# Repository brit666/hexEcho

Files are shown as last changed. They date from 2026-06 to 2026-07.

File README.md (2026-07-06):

# HexEcho 

Hexapod Assembly (rendered)

**Autonomous 18-DOF Hexapod Robot with Ultrasonic Navigation**

HexEcho is a fully autonomous six-legged walking robot built from scratch — custom CAD, hand-wired electronics, and original firmware. It uses a wave gait for maximum stability and an HC-SR04 ultrasonic sensor for obstacle detection and avoidance.

Built as a course project and designed as the physical platform for future reinforcement learning research.

---

## Quick Overview

| Property | Value |
|---|---|
| DOF | 18 (3 per leg × 6 legs) |
| Gait | Wave gait (1 leg at a time, 5 always grounded) |
| Controller | Arduino Nano |
| Servo Driver | 2× PCA9685 (I²C, 0x40 / 0x41) |
| Sensor | HC-SR04 ultrasonic |
| Power | 2S LiPo 7.4V 1000mAh |
| Chassis | Custom PETG, 3D printed |
| Weight | ~600g |

---

## Repository Structure

```
HexEcho/
├── firmware/
│   └── HexEcho_firmware.ino       # Main Arduino sketch
├── CAD/
│   ├── source/                    # Fusion 360 .f3d files
│   └── stl/                       # Export STLs for printing
│       ├── body_cylinder.stl
│       ├── cover_plate.stl
│       ├── body_hook.stl
│       ├── coxa_bracket.stl
│       ├── femur.stl
│       └── tibia.stl
│       └── print_details.txt
├── schematics/
│   └── HexEcho_schematic.png      # EasyEDA circuit diagram
├── docs/
│   └── HexEcho_Build_Manual.pdf  # Complete build manual (start here)
├── README.md
└── LICENSE
```

---

## Getting Started

Read **[`docs/HexEcho_Build_Manual.pdf`](docs/HexEcho_Build_Manual.pdf)** — it covers the full bill of materials, mechanical specs, wiring, firmware architecture, assembly steps, and calibration in detail.

**Quick steps:**
1. Print all STL files per the print settings in the manual
2. Source components from the BOM
3. Wire per the schematic
4. Flash `HexEcho_firmware.ino` to the Arduino Nano
5. Calibrate home angles and PWM range, then tune gait parameters
6. Deploy

---

## Dependencies

Install via Arduino IDE Library Manager before flashing:

- [Adafruit PWMServoDriver](https://github.com/adafruit/Adafruit-PWMServoDriver-Library)
- `Wire.h` (built-in)

---

## Roadmap

- **v1.0** — Wave gait + ultrasonic obstacle avoidance ✅ *(current)*
- **v2.0** — Reinforcement learning locomotion via Unreal Engine sim-to-real
- **v3.0** — Onboard camera + visual navigation
- **v4.0** — Adaptive terrain locomotion

---

## License

MIT License — see [LICENSE](LICENSE).

Hexapod Assembly pic trans


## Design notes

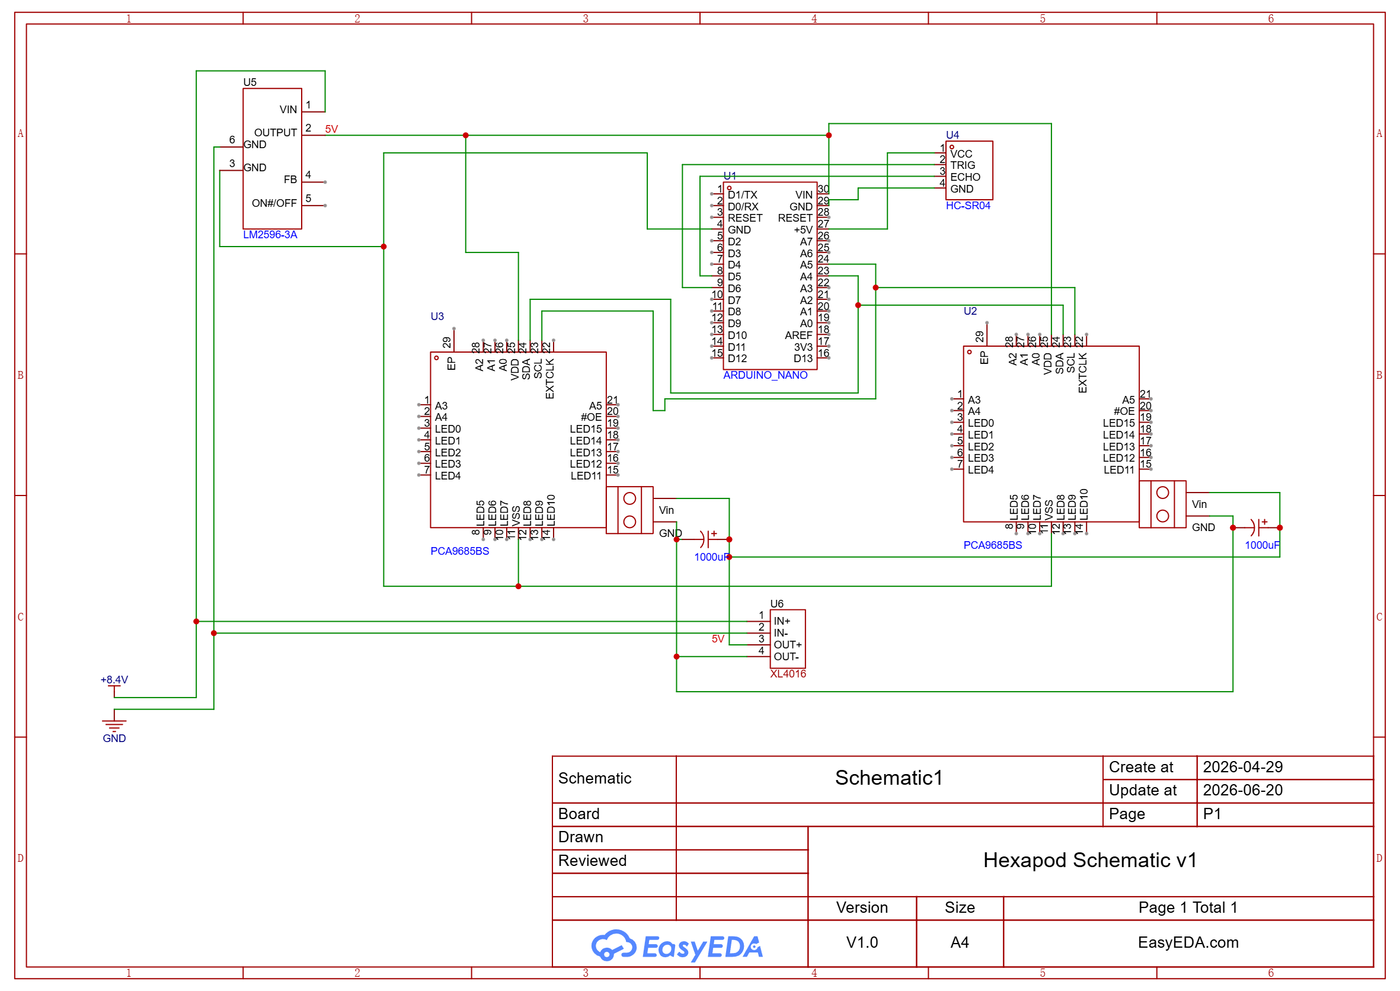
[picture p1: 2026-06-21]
schematics/HexEcho_schematic.png

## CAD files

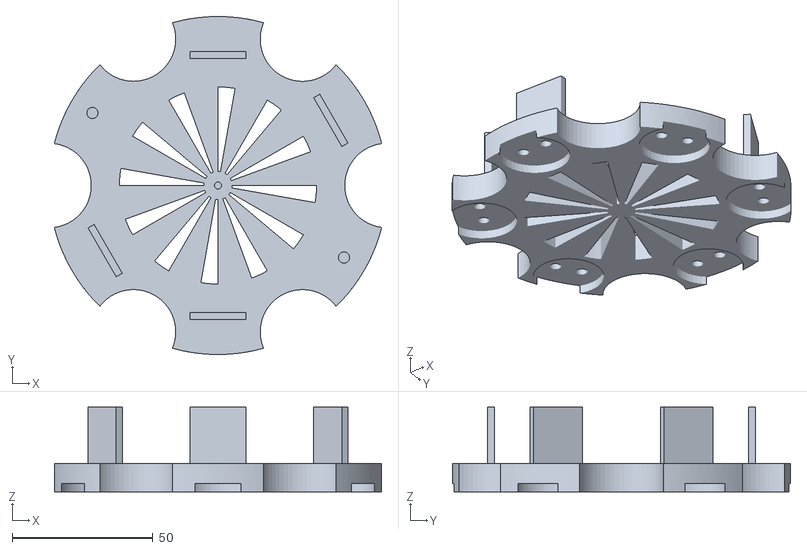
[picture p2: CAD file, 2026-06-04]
cad/stl/body_cylinder.stl
116.2 x 120.0 x 30.0

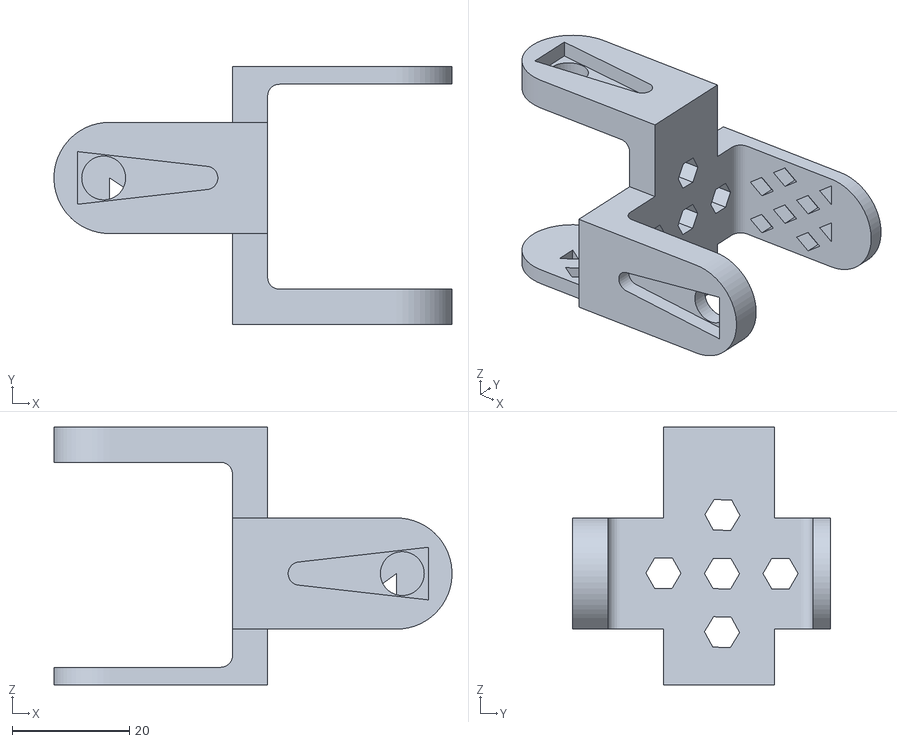
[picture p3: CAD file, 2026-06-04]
cad/stl/coxa_bracket.stl
68.0 x 44.0 x 44.0

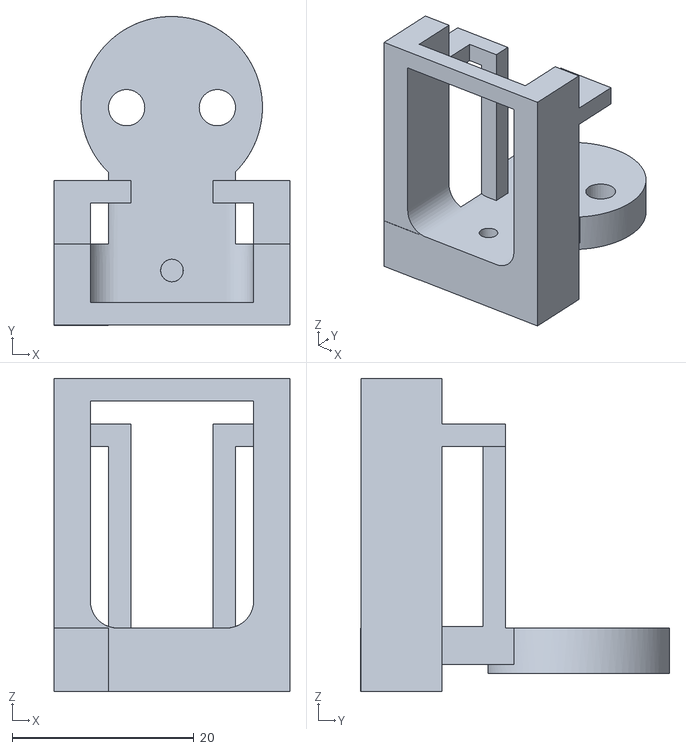
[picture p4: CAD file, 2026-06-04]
cad/stl/body_hook.stl
26.0 x 34.0 x 34.5

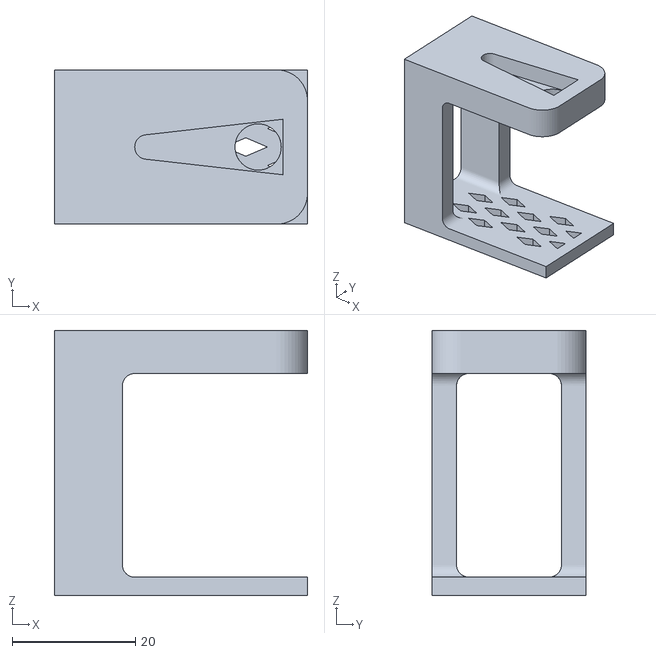
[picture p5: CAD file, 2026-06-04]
cad/stl/femur.stl
41.0 x 25.0 x 43.0

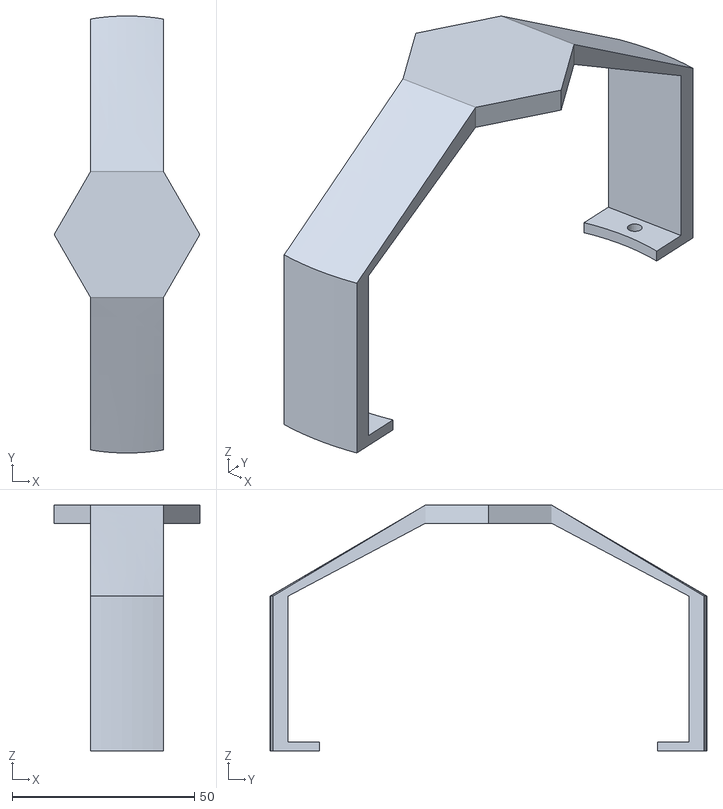
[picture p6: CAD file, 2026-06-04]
cad/stl/cover_plate.stl
40.0 x 120.0 x 67.5

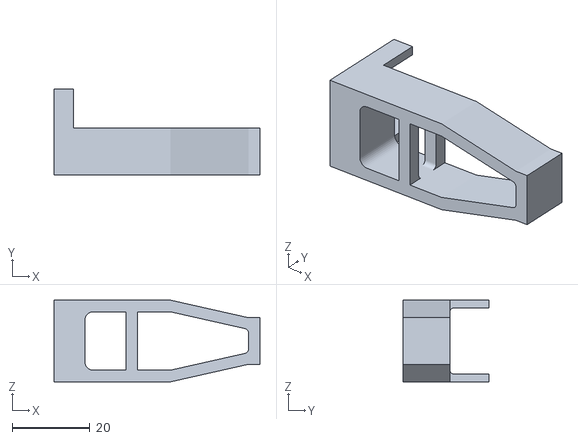
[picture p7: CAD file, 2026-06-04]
cad/stl/tibia.stl
53.0 x 22.0 x 21.0

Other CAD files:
cad/source/Hexapod Assembly.f3z
cad/source/body_cylinder.f3d
cad/source/body_hook.f3d
cad/source/cover_plate.f3d
cad/source/coxa_bracket.f3d
cad/source/femur.f3d
cad/source/tibia.f3d

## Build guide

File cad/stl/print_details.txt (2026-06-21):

Body - Infill 30%
Cover  - Infill 30%
Body Hook - Infill 40%
Coxa Bracket - Infill 40%
Femur - Infill 40%
Tibia - Infill 40%

wall : 3, Top layer 5, bottom layer 4

Material : PETG

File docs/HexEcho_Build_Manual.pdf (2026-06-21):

# HexEcho

# Complete Build Manual

## Mechanical Design • Electronics • Firmware • Assembly • Calibration

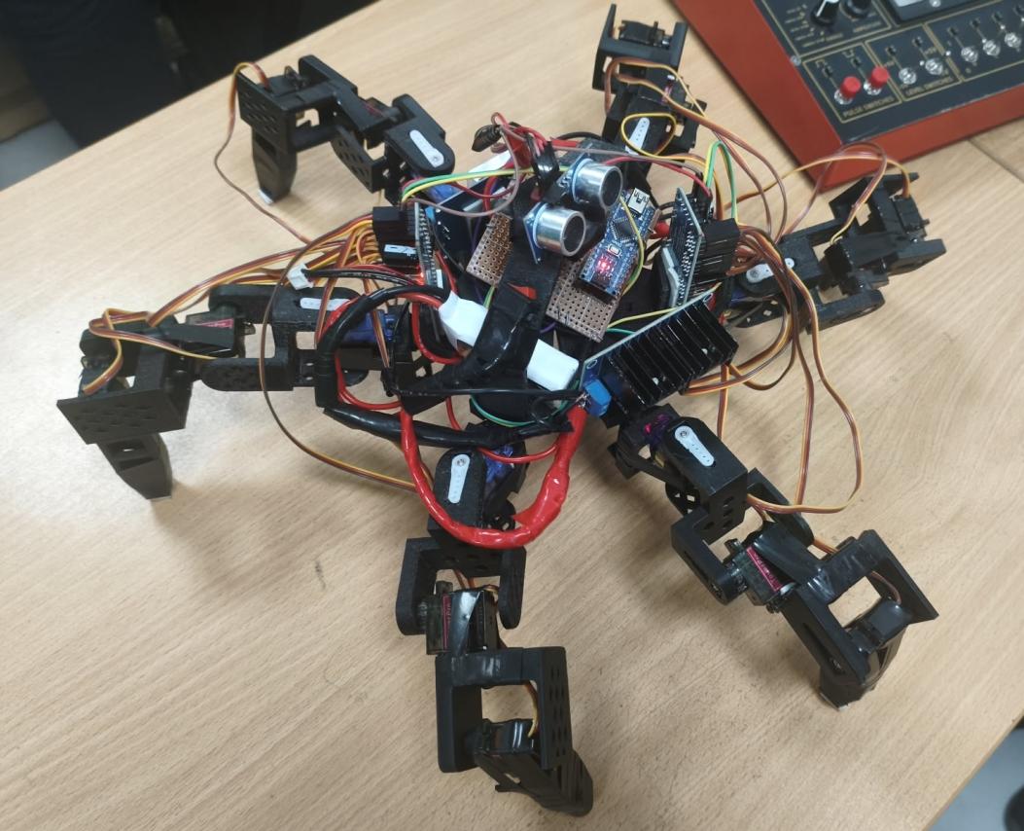
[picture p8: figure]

v1.0 — 2026

# Table of Contents

1. Overview 2. Bill of Materials 3. Tools Required 4. Safety Notes 5. Mechanical Design 6. Electronics Design 7. Firmware 8. Assembly Instructions 9. Exploded View & Final Assembly 10.Testing & Calibration 11.Troubleshooting 12.Roadmap 13.Appendix A — Full Firmware Source 14.Appendix B — Credits, License & Revision History

# 1. Overview

## HexEcho is an 18 degree-of-freedom autonomous hexapod robot. It uses a wave gait (one leg moves at a time) for maximum stability, an HC-SR04 ultrasonic sensor for obstacle detection, and a dual PCA9685 servo driver architecture controlled by

an Arduino Nano. The entire chassis is 3D printed in PETG.

This manual documents the complete build — mechanical parts, wiring, firmware, and assembly — in enough detail that the robot can be reproduced from these files.

## Top-Level Layout

## Leg numbering and orientation used throughout this manual and in the firmware:

[FRONT]
L0 | R3
L1 | R4
L2 | R5
[BACK]

L = left side (PCA9685 #1, address 0x40) R = right side (PCA9685 #2, address 0x41)

# 2. Bill of Materials

Component | Specification | Qty
Microcontroller | Arduino Nano (ATmega328P) | 1
Servo Driver | PCA9685 16-channel PWM driver | 2
Servo (Femur/Tibia) | MG90S metal gear micro servo | 12
Servo (Coxa) | SG90 micro servo | 6
Ultrasonic Sensor | HC-SR04 | 1
Battery | 2S LiPo 7.4V 1000mAh, T-plug | 1
Balance Charger | B3 2S/3S LiPo balance charger | 1
Voltage Monitor | 1S–8S cell voltage checker/alarm | 1
Buck Converter (servo rail) | XH-M404, 5A cont. / 8A peak, adjustable | 1
Buck Converter (logic rail) | LM2596 adjustable, 5V output | 1
Filter Capacitor | 1000µF 16V electrolytic | 2
Power Switch | Rocker or slide switch | 1
T-Plug Connector Pair | Male/female Deans-style | 1 pair
Wire — power | 22AWG stranded hookup wire (red/black) | ~2m
Wire — signal | Jumper wires (M-M, M-F, F-F) | 1 kit

Perfboard | ≥ 70×90mm | 1
M2 Heat Set Insert | Brass, knurled, for M2 screws | ~30
M3 Heat Set Insert | Brass, knurled, for M3 screws | ~30
M2 Machine Screws | 6–10mm length, carbon steel | ~40
M3 Machine Screws | 8–12mm length, carbon steel | ~20
Chassis Parts | Custom PETG 3D printed (see Section 5) | 1 set (20 parts)

# 3. Tools Required

- Soldering iron (40–60W) with stand, solder (60/40 or 63/37 rosin core), flux paste - Precision screwdriver set (PH00 / PH0 / PH1) - Small wire cutters / strippers - Digital multimeter - IPA (isopropyl alcohol, 70%+) for cleaning contacts - Computer with Arduino IDE installed - USB cable (data-capable, matching your Nano's port type)

# 4. Safety Notes

## BATTERY SAFETY: Always charge the LiPo battery with a balance charger (B3 or similar). Never charge an unattended battery. Never discharge below 3.0V per cell (set

your voltage alarm to trigger at 3.5V/cell for a safety margin). Disconnect the battery and

## the voltage checker after every session — both draw a small current even when the robot

is off.

## ASSEMBLY: Heat set inserts require the soldering iron at ~200–220°C for PETG. Thread

a sacrificial screw into the insert before installing to keep the threads clean.

# 5. Mechanical Design

All structural parts are modelled in Autodesk Fusion 360 and 3D printed in PETG.

## Final leg segment lengths used for inverse kinematics reference are listed below (measured from the assembled physical legs — confirm against your own build

before tuning IK).

Segment | Length (mm) | Notes
Coxa | 60.0 | Body joint to femur joint, includes bracket + horn
Femur | 50.0 | Femur joint to tibia joint, includes servo body
Tibia | 70.0 | Tibia joint to foot tip

## 5.1 Body Cylinder

## Houses the battery and all the electronics. Outer walls are used to mount pca9685

and two buck converters.

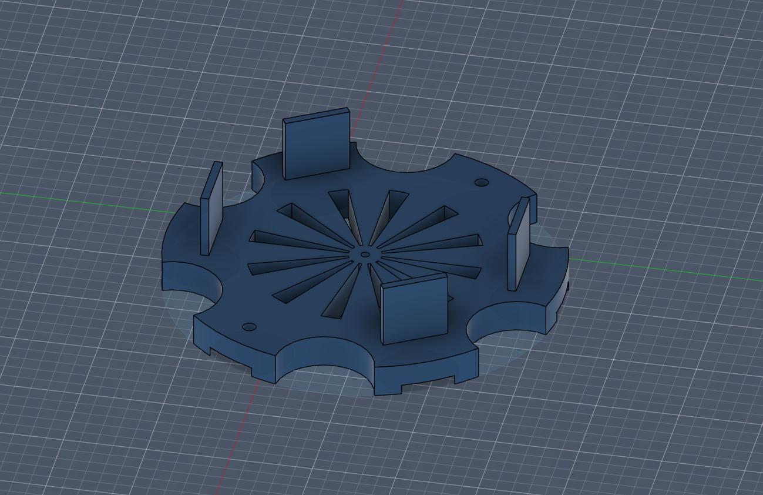
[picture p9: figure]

## 5.2 Cover Plate

Mounts to the body cylinder. Carries the ultrasonic sensor HC-SR04.

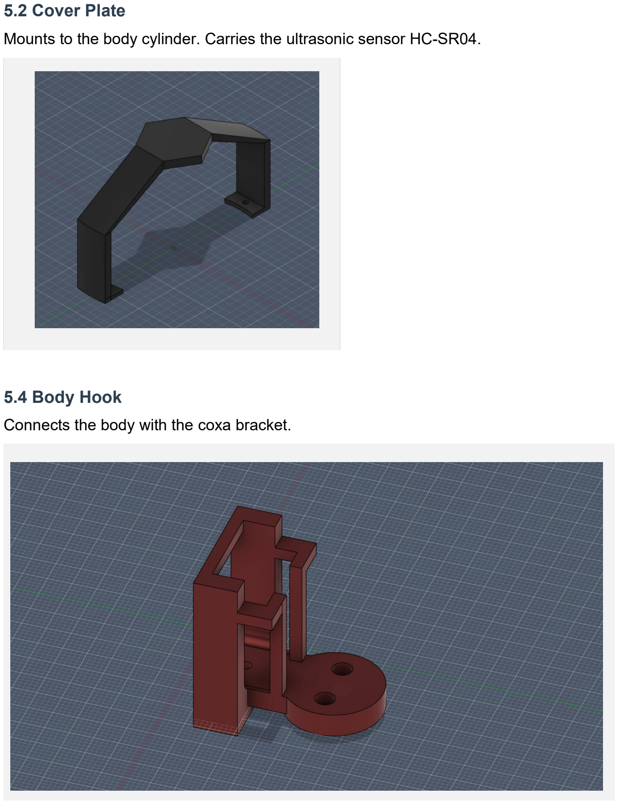
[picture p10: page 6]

## 5.4 Body Hook

Connects the body with the coxa bracket.

## 5.4 Coxa Bracket

## The most structurally complex part — mounts the coxa servo and connects the leg to the body hook. Walls increased to 6mm with R2–R5mm fillets at all thickness transitions after an early print failed by delaminating along the Z-axis at a thin-

wall/thick-wall junction.

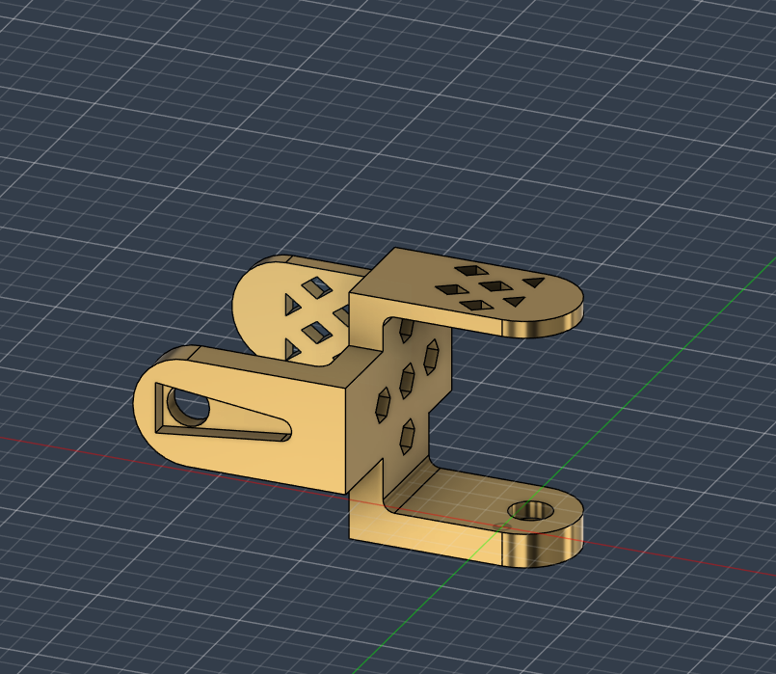
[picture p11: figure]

## 5.5 Femur Segment

## Houses the femur servo. Includes a cross-shaped horn socket (press fit, ~23mm

across, 3.5mm deep) plus a single M2 retention screw through the horn center.

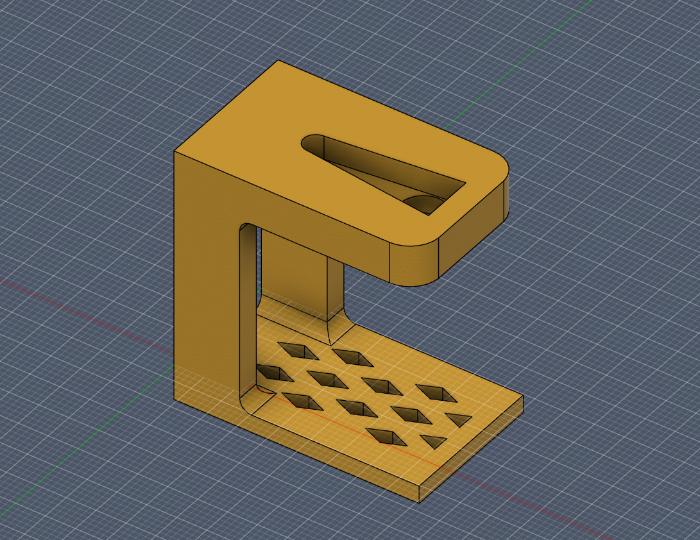
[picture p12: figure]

## 5.6 Tibia Segment

Passive segment, no servo. Tapered profile (wider at femur end, narrower at foot).

## Foot tip uses folded double-sided foam tape in place of a dedicated TPU foot cap for

grip on smooth surfaces.

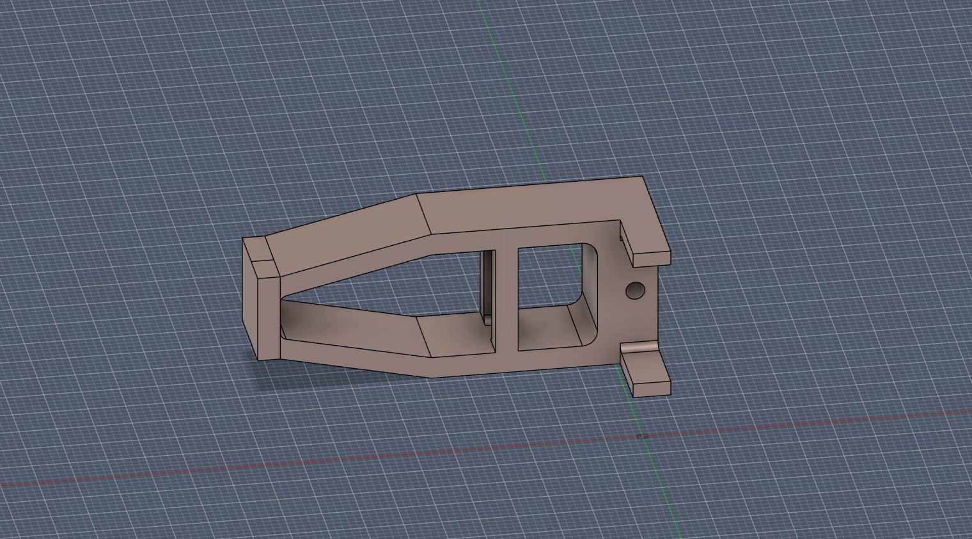
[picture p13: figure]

## 5.7 Fastener & Insert Reference

Use Case | Hardware | Hole Diameter | Depth
Cover → body | M2 + heat set insert | 2.5mm | 4mm
Servo body → bracket/segment | M2, direct into plastic | 2.5mm (clearance) / 2.2mm (self-tap) | —
Leg → leg / leg → body structural joint | M3 + heat set insert | 4mm | 6mm
M3 clearance (pass-through) | M3 screw shaft | 3.2–3.5mm | through

## 5.8 Print Settings

Part | Infill | Walls | Layer Height | Orientation
Body cylinder | 25–35% | 3 | 0.2mm | Open face down
Cover plate | 25–35% | 3 | 0.2mm | Flat
Body Hook | 35-40% | 3 | 0.2mm | Cylinders up
Coxa bracket | 35–40% | 4–6 (6mm wall) | 0.2mm | Broken wall parallel to bed
Femur | 35–40% | 3 (3mm wall) | 0.2mm | Longest face flat
Tibia | 35-40% | 3 (3mm wall) | 0.2mm | Longest face flat

## Material: PETG throughout. Nozzle: 0.4mm. Gyroid infill pattern preferred for fatigue

resistance.

# 6. Electronics Design

## 6.1 Full Circuit Schematic

## Complete schematic drawn in EasyEDA, covering all connections listed above plus

per-channel servo wiring.

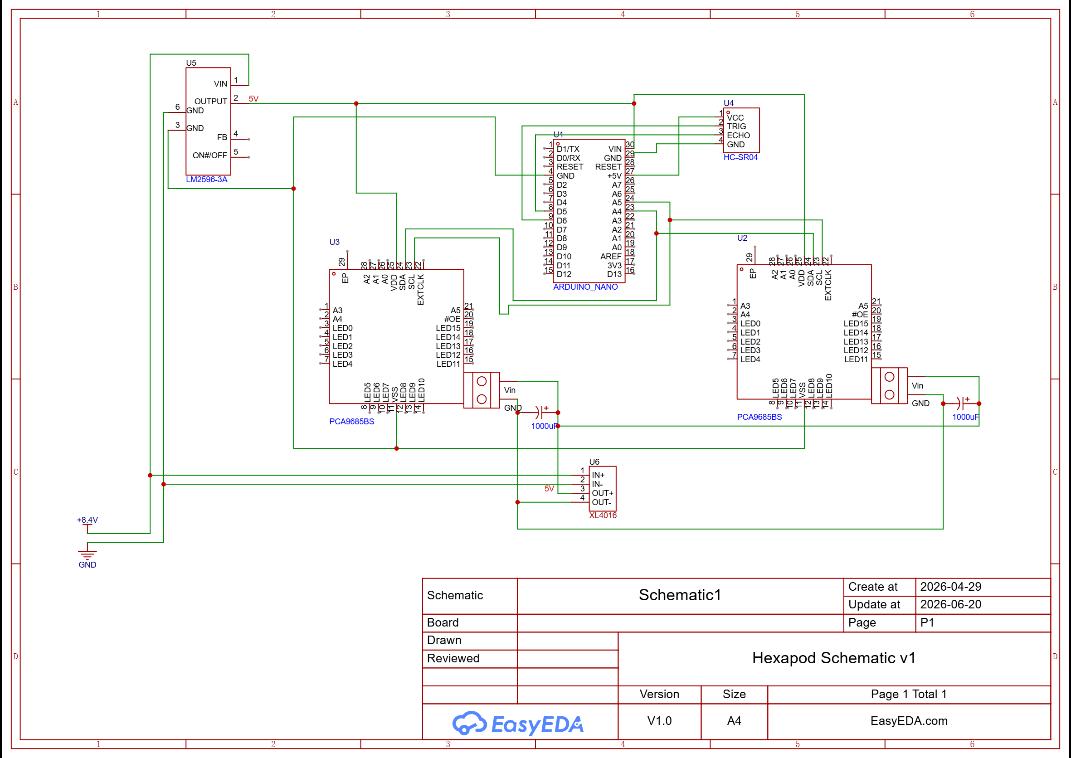
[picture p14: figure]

## 6.2 Power Architecture

## Two independent regulated rails from a single 2S LiPo, to isolate servo current spikes from the microcontroller's logic supply:

## - Servo rail — XH-M404 buck converter, set to 5V, feeds both PCA9685 V+ screw terminals. One 1000µF 16V capacitor across V+/GND at each

PCA9685 for local spike filtering.
- Logic rail — LM2596 buck converter, set to 5V, feeds Arduino Nano VIN.

## Nano's own 5V pin then powers both PCA9685 VCC (logic) pins and the HC-

SR04.

## 6.3 Microcontroller & Servo Driver Wiring

From | To | Purpose
Nano A4 (SDA) | PCA9685 #1 + #2 SDA | I2C data, shared bus
Nano A5 (SCL) | PCA9685 #1 + #2 SCL | I2C clock, shared bus
Nano 5V | PCA9685 #1 + #2 VCC | Logic power
Nano GND | Common ground rail | Logic ground
XH-M404 output + | PCA9685 #1 + #2 V+ (screw terminal) | Servo power
XH-M404 output − | Common ground rail | Servo ground
LM2596 output + | Nano VIN | Logic supply

## I2C ADDRESSING: PCA9685 #1 is address 0x40 (left legs 0,1,2). PCA9685 #2 has its A0

jumper pad bridged to set address 0x41 (right legs 3,4,5).

## 6.4 Sensor Wiring

HC-SR04 Pin | Connects To
VCC | Nano 5V
GND | Common ground rail
TRIG | Nano D6
ECHO | Nano D5

# 7. Firmware

## 7.1 Software Architecture

## The firmware is built around three core mechanisms:

## 1. Interpolation engine — every servo move is broken into 1° ticks (12ms apart by default) so all 18 servos glide smoothly and simultaneously rather than

snapping.

## 2. Hold delay — replaces plain delay() calls. Continuously re-sends the current PWM value to every servo during any pause, preventing servos from going

limp and working around occasional state loss on clone PCA9685 boards.
3. Per-leg state struct — each leg tracks its own current angle, target angle,

## PCA9685 board/channel assignment, and whether its coxa direction needs

mirroring (right-side legs).

## 7.2 Channel Map

Leg | Side | Board | Coxa Ch | Femur Ch | Tibia Ch
0 | Left — Front | 0x40 | 0 | 1 | 2
1 | Left — Mid | 0x40 | 3 | 4 | 5
2 | Left — Back | 0x40 | 6 | 7 | 8
3 | Right — Front | 0x41 | 0 | 1 | 2
4 | Right — Mid | 0x41 | 3 | 4 | 5
5 | Right — Back | 0x41 | 6 | 7 | 8

## 7.3 Key Parameters Reference

Parameter | Default | Description
COXA_HOME_DEG | 90° | Coxa angle when leg is centered
FEMUR_HOME_DEG | 60° | Femur angle in standing pose
TIBIA_HOME_DEG | 110° | Tibia angle for flat foot contact
STEP_COXA_SWING | 25° | Coxa travel per forward/back step
LIFT_FEMUR_DEG | 20° | Femur rise during swing phase
TURN_COXA_OFFSET | 22° | Extra coxa offset applied when turning
INTERP_STEP_DEG / INTERP_TICK_MS | 1° / 12ms | Interpolation smoothness/speed
PHASE_SETTLE_MS | 120ms | Pause after each gait phase
STEP_SETTLE_MS | 300ms | Pause after a leg finishes planting
CYCLE_SETTLE_MS | 700ms | Pause after a full 6-leg cycle
OBSTACLE_CM | 20cm | Distance threshold for obstacle avoidance
PWM_MIN / PWM_MAX | 150 / 600 | PCA9685 pulse counts for 0°/180° — tune per servo batch

## 7.4 Wave Gait Logic

## Wave order alternates sides to keep the support polygon balanced across the remaining five stance legs at all times:

WAVE_ORDER = { 0, 3, 1, 4, 2, 5 }
( L-Front → R-Front → L-Mid → R-Mid → L-Back → R-Back )

## Each leg step has three phases: Lift (femur rises, coxa stays centered) → Swing (coxa rotates toward target with femur still lifted) → Plant (femur lowers, foot returns

to ground).

## 7.5 Obstacle Avoidance Logic

4. Read HC-SR04. If clear (≥ OBSTACLE_CM) — step forward.
5. If blocked — turn left one cycle, re-check.
6. If still blocked — turn right twice (undo the left turn, then face right), re-check.

## 7. If still blocked — turn right once more (now facing roughly opposite original

heading), re-check.

## 8. If still blocked in all directions — return to home position and halt, holding all

servos at home indefinitely.

## 7.6 Calibration Procedure

## 9. Upload firmware with all home angles at default (90°/60°/110°). Power on

without legs attached.

## 10.Verify each servo reaches a sensible angle. If a servo overshoots or

undershoots, adjust PWM_MIN / PWM_MAX for that servo's batch.

## 11.Attach legs one at a time. Confirm the robot stands stably on all 6 legs at

home position before enabling gait.

## 12.Adjust FEMUR_HOME_DEG / TIBIA_HOME_DEG in small increments until

the robot stands level with all feet flat on the ground.

## 13.Test waveGait(+1) alone (call from setup() temporarily) and observe one full cycle. Adjust STEP_COXA_SWING and LIFT_FEMUR_DEG if the foot drags

or overshoots.
14.Re-enable obstacleAvoidanceLoop() in the main loop once gait looks stable.

# 8. Assembly Instructions

## 8.1 Heat Set Insert Installation

15.Thread a sacrificial M2/M3 screw into the insert to protect the threads. 16.Heat soldering iron to 200–220°C.

## 17.Place insert on the corresponding hole, press iron tip gently on top of the

insert.
18.Apply light downward pressure as the insert sinks flush with the surface.

## 19.Remove iron, hold still for ~15 seconds to cool, then remove the sacrificial

screw.

## 8.2 Leg Sub-Assembly

20.Mount SG90 into coxa bracket with M2 screws through the flange.
21.Mount MG90S into femur segment with M2 screws through the flange. 22.Mount MG90S into tibia mounting point on femur (tibia itself carries no servo).

## 23.Press-fit each servo horn into its corresponding cross socket, secure with a

single M2 screw through the horn center.

## 24.Join coxa → femur and femur → tibia with M2 screws into heat set inserts (2

screws per joint, ~16–18mm apart).

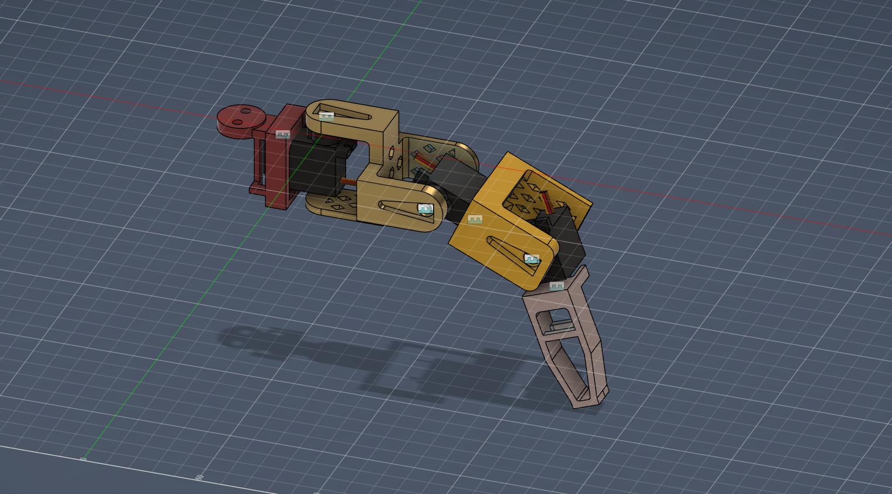
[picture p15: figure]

## 8.3 Body & Cover Assembly

25.Install M3 heat set inserts at all 6 leg mounting points on the body cylinder. 26.Attach all 6 leg assemblies to the body using M3 screws (2 per leg).

## 27.Insert battery into body cylinder, route T-plug and balance lead out through

the wiring slot.
28.Attach cover plate over body with M2 heat set inserts and screws.

29.Attach cover plate to body.

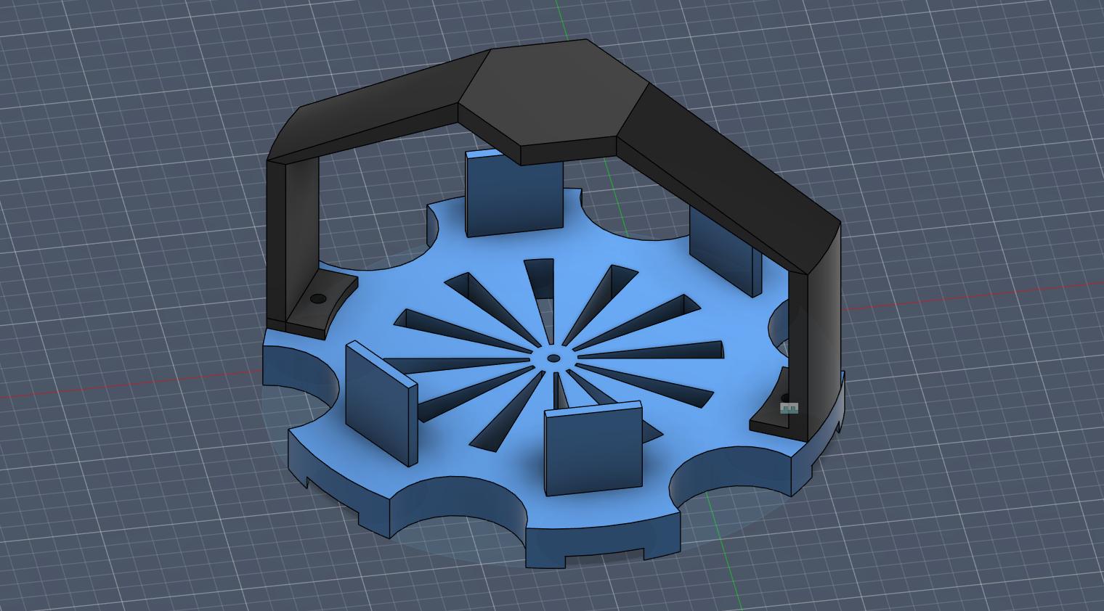
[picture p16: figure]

## 8.4 Electronics Mounting

## 30.Mount Arduino Nano on the body cylinder using M2 screws or double sided

foam tape.

## 31.Mount both PCA9685 boards using double-sided foam tape with the outer

walls.
32.Mount both buck converters using double-sided foam tape.
33.Mount HC-SR04 on the cover plate, elevated above leg sweep height.

## 8.5 Wiring Sequence

34.Wire battery T-plug (female) to power switch using 22AWG wire. 35.Wire switch to both buck converter inputs.

## 36.Set both buck converters to 5V output using a multimeter or their onboard

display before connecting any load.

## 37.Wire XH-M404 output to both PCA9685 V+ terminals, with one 1000µF

capacitor at each.
38.Wire LM2596 output to Nano VIN.
39.Wire Nano 5V/GND to both PCA9685 VCC/GND and to HC-SR04 VCC/GND. 40.Wire Nano A4/A5 to both PCA9685 SDA/SCL.

41.Wire Nano D7/D8 to HC-SR04 TRIG/ECHO.

## 42.Connect all 18 servos to their assigned PCA9685 channels per the Channel

Map (Section 7.2).

# 9. Exploded View & Final Assembly

## 9.1 Exploded View

## All major components shown separated along their assembly axis, illustrating how

each part stacks relative to the others.

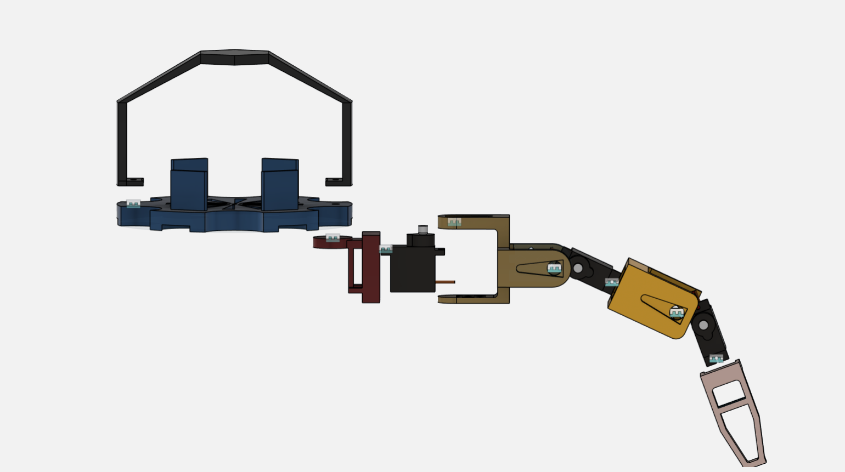
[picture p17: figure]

## 9.2 Final Assembled Model

Fully joined CAD assembly, representing the completed robot prior to wiring.

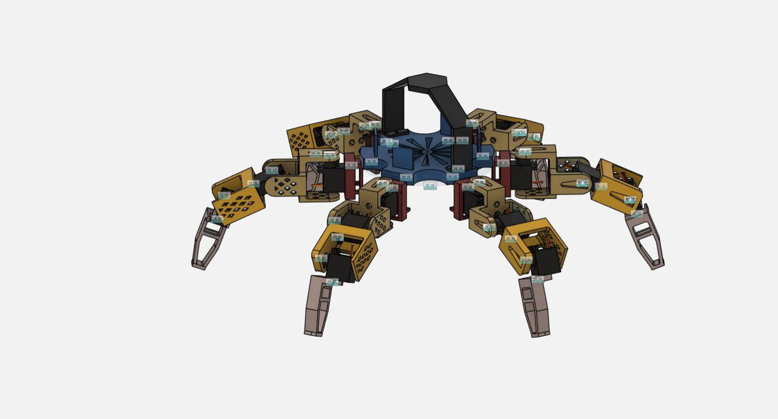
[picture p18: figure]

# 10. Testing & Calibration Checklist

## - [ ] All 18 servos respond individually via PCA9685 (no legs attached) - [ ] Buck converter outputs verified at 5V before connecting any board - [ ] Robot stands stably on all 6 legs at home position - [ ] HC-SR04 readings stable and accurate (compare against tape measure at

10/30/50cm)

- [ ] Single wave gait cycle completes without any leg dragging or losing balance - [ ] Obstacle avoidance correctly triggers stop + turn sequence - [ ] Battery voltage alarm triggers correctly at set threshold - [ ] No wire or connector becomes warm to the touch during 5+ minutes of continuous walking

# 11. Troubleshooting

Symptom | Likely Cause | Fix
Servo grinds/buzzes | Loose/intermittent signal connection | Solder signal wire instead of friction-fit jumper

### Print cracks along Z-axis at wall transition

### Sharp corner stress concentration + thin wall under overhang

### Add fillet (R3–R5mm) at the transition, increase local wall thickness

Servo wobbles in single-screw mount | Clone servo flange not flat / single fastening point | Add epoxy on contact faces, or wrap joint with wire + tape as a field fix
Arduino resets/browns out during gait | Servo current spike on shared power rail | Verify dual buck converter separation, confirm 1000µF capacitors are installed at each PCA9685
IDE can't upload, "programmer not responding" | Wrong bootloader selected for clone Nano | Try both Old Bootloader and standard ATmega328P options in Tools → Processor
False obstacle triggers during gait | Ultrasonic beam clipping a swinging leg | Mount HC-SR04 higher, or add consecutive-reading filtering in firmware
Robot tips over while walking | Home position not centered, or step height/length too aggressive for current gait | Re-tune home angles per leg; reduce STEP_COXA_SWING and LIFT_FEMUR_DEG

# 12. Roadmap

## - v1.0 (current) — wave gait locomotion, ultrasonic obstacle avoidance - v2.0 — reinforcement learning locomotion trained in Unreal Engine simulation - v3.0 — onboard camera + visual navigation - v4.0 — sim-to-real policy transfer to physical platform

# Appendix A — Full Firmware Source

## Complete Arduino sketch (HexEcho_firmware.ino). The authoritative copy lives in

/firmware in the repository — this listing is for offline reference.

/*
* ================================================================ * HexEcho Hexapod Firmware — v2 (with interpolation engine)
* ================================================================ * Hardware:
* Arduino Nano, 2x PCA9685 (0x40 / 0x41), HC-SR04, MG90S + SG90 *
* Gait: Wave gait (1 leg at a time) — most stable
* Motion: All servo moves go through the interpolation engine.
* | Servos never snap — they glide from current to target.
*
* ----------------------------------------------------------------* CHANNEL MAP
* ----------------------------------------------------------------* PCA0 (0x40) — LEFT SIDE legs 0,1,2 (Front / Mid / Back)
* | Ch 0,1,2 = Leg0 Coxa, Femur, Tibia
* | Ch 3,4,5 = Leg1 Coxa, Femur, Tibia
* | Ch 6,7,8 = Leg2 Coxa, Femur, Tibia
*
* PCA1 (0x41) — RIGHT SIDE legs 3,4,5 (Front / Mid / Back)
* | Ch 0,1,2 = Leg3 Coxa, Femur, Tibia
* | Ch 3,4,5 = Leg4 Coxa, Femur, Tibia
* | Ch 6,7,8 = Leg5 Coxa, Femur, Tibia
*
* Top-view layout (front = top):
* | [FRONT]
* | L0 | R3
* | L1 | R4
* | L2 | R5
* | [BACK]
*
* ----------------------------------------------------------------* HOME POSITION SUMMARY (what the code commands on boot)
* ----------------------------------------------------------------
* | Coxa = 90° (straight sideways)
* | Femur = 60° (tilted slightly forward-down for a standing pose)
* | Tibia = 110° (angled to plant foot flat on ground)
*
* Mount each servo FIRST to these angles — see the mounting guide PDF. * ================================================================
*/

#include <Wire.h>

#include <Adafruit_PWMServoDriver.h>

// ================================================================ // USER-CONFIGURABLE — edit to match your hardware
// ================================================================

// Leg segment lengths in mm (only used for reference / future IK)
#define COXA_LEN_MM | 60.0f

#define FEMUR_LEN_MM | 50.0f

#define TIBIA_LEN_MM | 70.0f

// Home stance angles
#define COXA_HOME_DEG | 90

#define FEMUR_HOME_DEG | 60

#define TIBIA_HOME_DEG 110

// Gait geometry
#define STEP_COXA_SWING | 25 | // degrees coxa travels per step

#define LIFT_FEMUR_DEG | 20 | // degrees femur rises during swing

#define TURN_COXA_OFFSET 22 | // extra coxa offset used during rotation

// Interpolation speed — lower = slower / smoother
// INTERP_STEP_DEG: how many degrees to advance per tick
// INTERP_TICK_MS : ms between each tick
// At 1 deg / 15 ms → a 30-degree move takes ~450 ms
#define INTERP_STEP_DEG | 1 | // degrees per tick (keep at 1 for smoothest)

#define INTERP_TICK_MS | 12 | // ms per tick

// Pauses between gait phases (on top of interpolation time)
#define PHASE_SETTLE_MS 120 | // brief settle after each phase completes

#define STEP_SETTLE_MS | 300 | // pause after each leg finishes its step

#define CYCLE_SETTLE_MS 700 | // pause after a full 6-leg cycle — SAFE POWER-OFF WINDOW

// HC-SR04 pins
#define TRIG_PIN | 7

#define ECHO_PIN | 8

// Obstacle distance threshold
#define OBSTACLE_CM 20

// PCA9685 pulse range — tune if servos don't reach 0° or 180°
#define PWM_MIN 150 | // pulse count at 0°

#define PWM_MAX 600 | // pulse count at 180°

// ================================================================ // PCA9685 INSTANCES
// ================================================================ Adafruit_PWMServoDriver pca0 = Adafruit_PWMServoDriver(0x40); Adafruit_PWMServoDriver pca1 = Adafruit_PWMServoDriver(0x41);

// ================================================================ // LEG STRUCTURE
// currentDeg[] = live angles (updated every interpolation tick) // targetDeg[] = where we want to go
// mirrorCoxa = true for right-side legs (inverts coxa direction) // ================================================================ struct Leg {
uint8_t board; | // 0 = pca0, 1 = pca1
uint8_t ch[3]; | // channel indices: 0=coxa 1=femur 2=tibia
float | currentDeg[3]; | // current servo angle (float for smooth interp)
int | targetDeg[3]; | // target angle
bool | mirrorCoxa; | // true = invert coxa for right-side legs
};

Leg legs[6];

// ================================================================ // LOW-LEVEL SERVO WRITE
// ================================================================

uint16_t degToPulse(float deg) {
deg = constrain(deg, 0.0f, 180.0f);
return (uint16_t)map((long)(deg * 10), 0, 1800, PWM_MIN, PWM_MAX); }

void writeServoRaw(uint8_t board, uint8_t channel, float deg) { uint16_t pulse = degToPulse(deg);
if (board == 0) pca0.setPWM(channel, 0, pulse);
else | pca1.setPWM(channel, 0, pulse);
}

// Flush current angles to hardware for one leg
void flushLeg(uint8_t li) {
Leg& L = legs[li];
float coxaDeg = L.mirrorCoxa ? (180.0f - L.currentDeg[0]) : L.currentDeg[0];

writeServoRaw(L.board, L.ch[0], coxaDeg); writeServoRaw(L.board, L.ch[1], L.currentDeg[1]); writeServoRaw(L.board, L.ch[2], L.currentDeg[2]);
}

// ================================================================ // INTERPOLATION ENGINE
// Moves all 6 legs from their currentDeg toward their targetDeg // one INTERP_STEP_DEG tick at a time.
// Returns only when all legs have reached their targets.
// ================================================================ void interpolateAllLegs() {
bool moving = true;
while (moving) {
moving = false;
for (uint8_t li = 0; li < 6; li++) {
for (uint8_t j = 0; j < 3; j++) {
float diff = legs[li].targetDeg[j] - legs[li].currentDeg[j];
if (abs(diff) > 0.5f) {
moving = true;
float step = constrain(diff, -(float)INTERP_STEP_DEG, (float)INTERP_STEP_DEG); legs[li].currentDeg[j] += step;
} else {
legs[li].currentDeg[j] = (float)legs[li].targetDeg[j];
}
}
flushLeg(li);
}
if (moving) delay(INTERP_TICK_MS);
}
// One final flush after motion completes — ensures all servos are exactly on target for (uint8_t li = 0; li < 6; li++) flushLeg(li);
}

// ================================================================ // HOLD DELAY
// Replaces all bare delay() calls during pauses.
// Re-flushes every servo every HOLD_REFRESH_MS during the wait // so the PCA9685 keeps asserting PWM and servos don't go limp. // Also catches clone PCA9685 boards that occasionally lose state. // ================================================================ #define HOLD_REFRESH_MS 20 // re-send PWM every 20ms during holds

void holdDelay(uint32_t ms) {
uint32_t start = millis();
while (millis() - start < ms) {
for (uint8_t li = 0; li < 6; li++) flushLeg(li); delay(HOLD_REFRESH_MS);
}
}

// Convenience: set target for one leg's joint (0=coxa,1=femur,2=tibia) void setTarget(uint8_t li, uint8_t joint, int deg) { legs[li].targetDeg[joint] = constrain(deg, 0, 180);
}

// Set all three joints of one leg at once
void setLegTarget(uint8_t li, int coxaDeg, int femurDeg, int tibiaDeg) { legs[li].targetDeg[0] = constrain(coxaDeg, 0, 180); legs[li].targetDeg[1] = constrain(femurDeg, 0, 180); legs[li].targetDeg[2] = constrain(tibiaDeg, 0, 180);
}

// ================================================================ // LEG TABLE INIT
// ================================================================ void initLegsTable() {
// Helper lambda-style inline — sets a leg entry
// Left legs (0,1,2): mirrorCoxa = false

// Right legs (3,4,5): mirrorCoxa = true
struct LegInit { uint8_t board; uint8_t c, f, t; bool mirror; }; const LegInit cfg[6] = {
{0, 0, 1, 2, false}, // Leg0 L-Front
{0, 3, 4, 5, false}, // Leg1 L-Mid
{0, 6, 7, 8, false}, // Leg2 L-Back {1, 0, 1, 2, true }, // Leg3 R-Front {1, 3, 4, 5, true }, // Leg4 R-Mid {1, 6, 7, 8, true }, // Leg5 R-Back };
for (uint8_t i = 0; i < 6; i++) {
legs[i].board | = cfg[i].board;
legs[i].ch[0] | = cfg[i].c;
legs[i].ch[1] | = cfg[i].f;
legs[i].ch[2] | = cfg[i].t;
legs[i].mirrorCoxa = cfg[i].mirror; // Start current and target both at home legs[i].currentDeg[0] = COXA_HOME_DEG; legs[i].currentDeg[1] = FEMUR_HOME_DEG; legs[i].currentDeg[2] = TIBIA_HOME_DEG; legs[i].targetDeg[0] = COXA_HOME_DEG; legs[i].targetDeg[1] = FEMUR_HOME_DEG; legs[i].targetDeg[2] = TIBIA_HOME_DEG; }
}

// ================================================================ // HOME POSITION
// Moves legs to home one at a time so the bot doesn't lurch.
// ================================================================ void goHome() {
Serial.println(F("[HOME] Moving to home position..."));
for (uint8_t i = 0; i < 6; i++) {
setLegTarget(i, COXA_HOME_DEG, FEMUR_HOME_DEG, TIBIA_HOME_DEG); interpolateAllLegs();
holdDelay(PHASE_SETTLE_MS);
}
holdDelay(CYCLE_SETTLE_MS); Serial.println(F("[HOME] Done."));
}

// ================================================================ // SINGLE LEG STEP (lift → swing → plant)
// direction : +1 = forward, -1 = backward
// coxaExtra : extra coxa offset for turning
//
// While one leg moves, the others stay put (wave gait).
// ================================================================
void stepLeg(uint8_t li, int direction, int coxaExtra) {
int targetCoxa = COXA_HOME_DEG + (direction * STEP_COXA_SWING) + coxaExtra; targetCoxa = constrain(targetCoxa, 45, 135);

// --- Phase 1: Lift ---
setLegTarget(li, COXA_HOME_DEG,
| FEMUR_HOME_DEG - LIFT_FEMUR_DEG,
| TIBIA_HOME_DEG);
interpolateAllLegs();
holdDelay(PHASE_SETTLE_MS);

// --- Phase 2: Swing ---
setLegTarget(li, targetCoxa,
| FEMUR_HOME_DEG - LIFT_FEMUR_DEG,
| TIBIA_HOME_DEG);
interpolateAllLegs();
holdDelay(PHASE_SETTLE_MS);

// --- Phase 3: Plant ---
setLegTarget(li, targetCoxa,
| FEMUR_HOME_DEG,
| TIBIA_HOME_DEG);

interpolateAllLegs();
holdDelay(STEP_SETTLE_MS); // *** SAFE POWER-OFF POINT — leg planted, stable *** }

// ================================================================
// RESET ALL COXAS TO HOME (after a full gait cycle)
// ================================================================ void resetAllCoxas() {
for (uint8_t i = 0; i < 6; i++) {
setTarget(i, 0, COXA_HOME_DEG);
}
interpolateAllLegs();
holdDelay(PHASE_SETTLE_MS);
}

// ================================================================ // WAVE GAIT — FORWARD / BACKWARD
// Sequence: L-Front → R-Front → L-Mid → R-Mid → L-Back → R-Back // (alternates sides to keep weight balanced)
// ================================================================ const uint8_t WAVE_ORDER[6] = {0, 3, 1, 4, 2, 5};

void waveGait(int direction) {
for (uint8_t i = 0; i < 6; i++) { stepLeg(WAVE_ORDER[i], direction, 0);
}
resetAllCoxas();
holdDelay(CYCLE_SETTLE_MS); // *** SAFE POWER-OFF WINDOW ***
}

void stepForward() { Serial.println(F("[GAIT] Forward")); waveGait(+1); } void stepBackward() { Serial.println(F("[GAIT] Backward")); waveGait(-1); }

// ================================================================
// ROTATION (turn in place)
// rotDir: +1 = left, -1 = right
//
// Left turn: left legs push back, right legs push forward
// Right turn: left legs push forward, right legs push back
// ================================================================ void rotateStep(int rotDir) {
for (uint8_t i = 0; i < 6; i++) {
uint8_t li = WAVE_ORDER[i];
// Legs 0,1,2 = left → opposite direction to rotDir // Legs 3,4,5 = right → same direction as rotDir int legDir = (li < 3) ? (-rotDir) : (rotDir); int coxaExtra = TURN_COXA_OFFSET * legDir; stepLeg(li, legDir, coxaExtra);
}
resetAllCoxas();
holdDelay(CYCLE_SETTLE_MS);
}

void turnLeft() { Serial.println(F("[TURN] Left")); rotateStep(+1); } void turnRight() { Serial.println(F("[TURN] Right")); rotateStep(-1); }

// ================================================================
// HC-SR04 SENSOR
// ================================================================ float getDistanceCm() {
digitalWrite(TRIG_PIN, LOW);
delayMicroseconds(4);
digitalWrite(TRIG_PIN, HIGH);
delayMicroseconds(10);
digitalWrite(TRIG_PIN, LOW);
long dur = pulseIn(ECHO_PIN, HIGH, 26000UL); // timeout ~4.5m if (dur == 0) return 999.0f;
return (dur * 0.0343f) / 2.0f;
}

bool obstacleAhead() {
float d = getDistanceCm(); Serial.print(F("[SENSOR] ")); Serial.print(d, 1);
Serial.println(F(" cm"));
return (d < OBSTACLE_CM);
}

// ================================================================ // OBSTACLE AVOIDANCE
//
// Logic:
// | 1. Clear ahead → step forward
// | 2. Blocked | → try LEFT
// | 3. Still blocked → turn RIGHT x2 (undo left, then face right)
// | 4. Still blocked → turn RIGHT once more (~facing backward)
// | 5. Still blocked → go home, halt (safe power-off)
// ================================================================ void obstacleAvoidanceLoop() {
Serial.println(F("--- Checking ahead ---"));

if (!obstacleAhead()) {
| stepForward();
| return;
}

Serial.println(F("[NAV] Obstacle! Trying LEFT..."));
| turnLeft();
if (!obstacleAhead()) { stepForward(); return; }

Serial.println(F("[NAV] Still blocked. Turning RIGHT x2..."));
| turnRight(); | // undo left → back to original heading
| turnRight(); | // now facing right
if (!obstacleAhead()) { stepForward(); return; }

Serial.println(F("[NAV] Still blocked. Turning RIGHT once more..."));
| turnRight(); | // now facing ~180° from original
if (!obstacleAhead()) { stepForward(); return; }

Serial.println(F("[NAV] ALL DIRECTIONS BLOCKED. Returning home and halting."));
| goHome();
while (true) holdDelay(500); // keeps servo PWM alive at home position
}

// ================================================================
// SETUP
// ================================================================ void setup() {
| Serial.begin(9600);
Serial.println(F("=== HexEcho booting ==="));
| Wire.begin();

pca0.begin(); pca0.setPWMFreq(50); pca1.begin(); pca1.setPWMFreq(50);
| delay(200);

pinMode(TRIG_PIN, OUTPUT); pinMode(ECHO_PIN, INPUT);

| initLegsTable();

// Flush initial angles to hardware immediately (no snap — already at home) for (uint8_t i = 0; i < 6; i++) flushLeg(i);
| holdDelay(300);

// Smooth move to home (in case servos powered up in unknown position) goHome();

Serial.println(F("=== Ready ==="));
holdDelay(1000);
}

// ================================================================ // MAIN LOOP
// ================================================================ void loop() {
obstacleAvoidanceLoop();
holdDelay(CYCLE_SETTLE_MS);
}

# Appendix B — Credits, License & Revision History

## Credits

## Designed, built, and documented as an independent course project — mechanical

design, electronics, and firmware all developed from first principles.

## - Mechanical design — Autodesk Fusion 360 - Circuit schematic — EasyEDA - Firmware — Arduino IDE, Adafruit_PWMServoDriver library - Chassis fabrication — PETG FDM 3D printing

## License

## This project is released under the MIT License. See LICENSE in the repository root

for full terms.

## Revision History

Version | Date | Changes
v1.0 | 2026 | Initial build — wave gait locomotion, ultrasonic obstacle avoidance

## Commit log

2026-06-04 uploaded cad model
    [Body Base.stl, Body Hook.stl, Coxa Bracket.stl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]
2026-06-21 Create cad folder
2026-06-21 Add print_details.txt to the project structure
